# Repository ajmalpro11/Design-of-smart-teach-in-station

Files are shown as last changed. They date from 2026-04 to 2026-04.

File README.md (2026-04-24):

# Teach-In Station: Automated Warehouse Classification System

<p align="center">
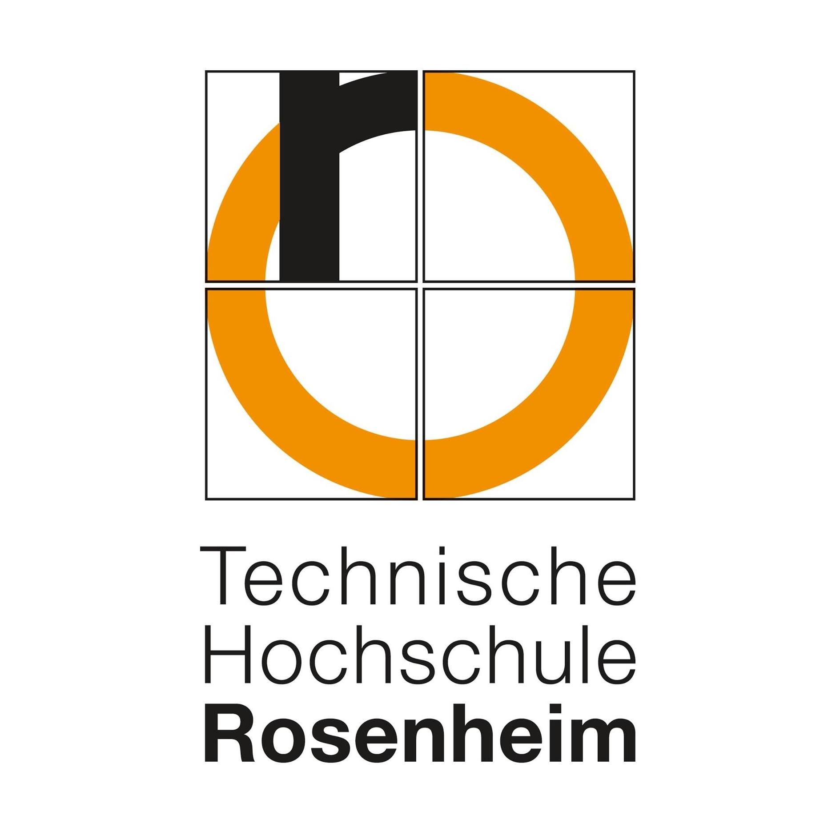
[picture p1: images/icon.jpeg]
  
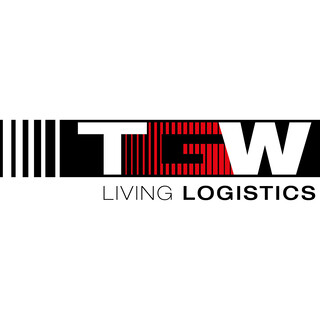
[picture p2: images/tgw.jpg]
  
</p>

**Mechanical Design | Summer Semester 2024** **Technische Hochschule Rosenheim | Group D** *In collaboration with TGW Logistics Group GmbH*

---

## 🏛️ Project Context
This project was developed as part of the **Mechanical Design** curriculum at **TH Rosenheim** for the Summer Semester 2024. The design was created in direct collaboration with **TGW Logistics Group GmbH** to solve real-world challenges in automated logistics.

## 📝 Project Overview
The "Teach-In Station" is an innovative solution designed to automate the identification of product attributes. Unlike standard systems that only track barcodes, this station analyzes:

<p align="center">
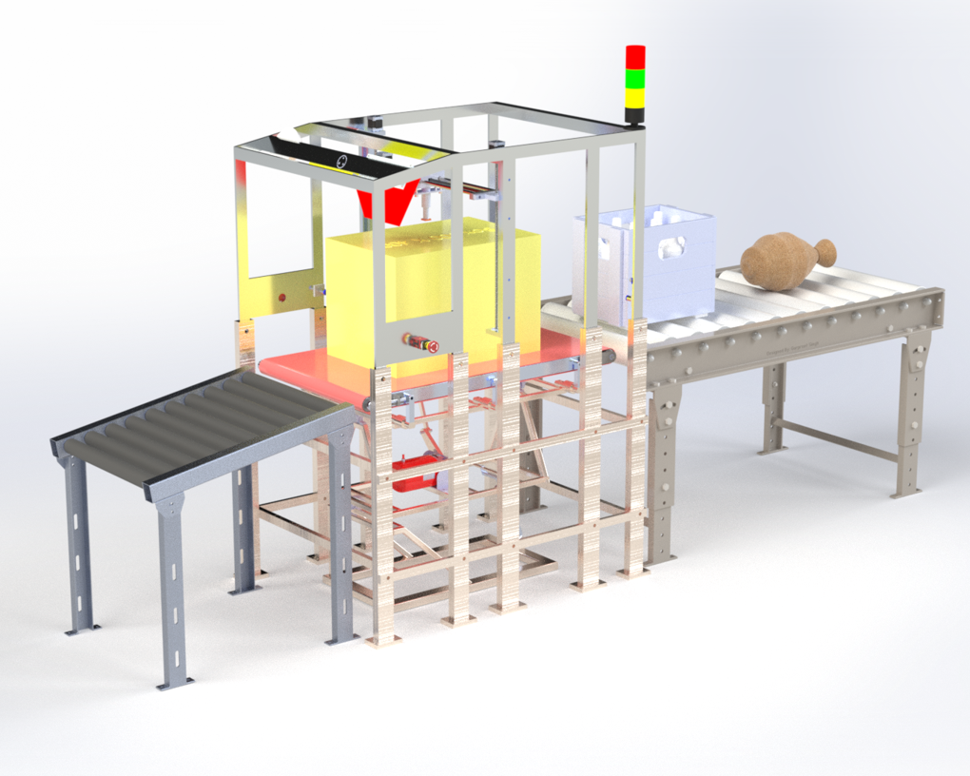
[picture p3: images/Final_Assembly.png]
  
</p> 

* **Physical Dimensions & Shape:** Identifying "Regular" vs. "Ugly" (irregular) objects using 3D camera profiling.
* **Stiffness:** Measuring structural integrity via a custom probe mechanism ($F = k \cdot \delta$).
* **Material Properties:** Detecting center of mass, liquid content (sloshing detection), and friction coefficients.

## 🛠️ System Assemblies
The repository contains design data for the following core modules:
1. **/Cage-Assembly:** The main structural frame housing the 3D camera, ultrasonic sensors, and weighing system.
2. **/Stiffness-Mechanism:** Precision assembly utilizing stepper motors, lead screws, and load cells for pressure testing.
3. **/Swivelling-Table:** A tilting platform designed for center of mass calculation and liquid detection.
4. **/Gravity-Conveyor:** The sorting mechanism for final product distribution.

## 📊 Technical Specifications
* **Final Concept:** Concept 7 (Selected for high reliability and space efficiency).
* **Total Estimated Cost:** **€9,118.76** (Budget limit: €15,000.00).
* **Software Logic:** Implementation of the **TGW Decision Code** (evaluating Weight, Dimensions, Geometry, and Stiffness).
* **Safety:** Integrated emergency stop, smoke detection, and optimized LED lighting for sensor precision.

## 👥 Group D Team Members
* Ajumal Shamsudeen 
* Aniket Barotkar
* Azmath Dar Khan
* Francis Almeida
* Udit Kumar
* Yazmin Soto

---

## 📂 Repository Structure
```text
├── docs/                 # Final Report and Technical Documentation
├── cad-models/           # STEP/STL files for all assemblies
├── images/          
├── logic/                # TGW Decision Code flowcharts and scripts
└── README.md             # Project Overview

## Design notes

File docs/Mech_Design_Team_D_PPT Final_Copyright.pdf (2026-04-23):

# MECHANICAL DESIGN

## THE DESIGN OF A SMART TEACH-IN STATION

08/07/2024

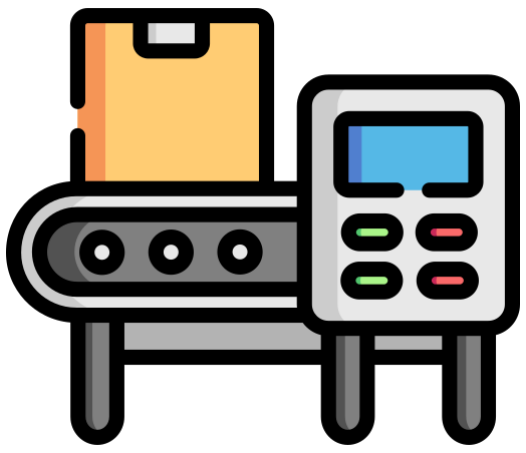
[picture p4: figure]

### Guided By: Dr. Ihab Ragai

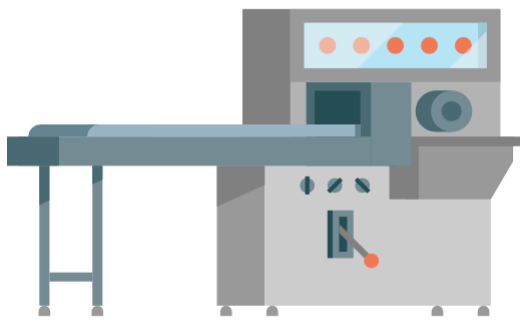
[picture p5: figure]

# Group-D

## Team members:

### •Ajumal Shamsudeen- 1067369 •Aniket Barotkar- 1066937 •Azmath Dar Khan- 1069574 •Francis Almeida- 1070842 •Udit Kumar- 1065691 •Yazmin Soto- 1066292

# TIMELINE

ABOUT PRESENTATION

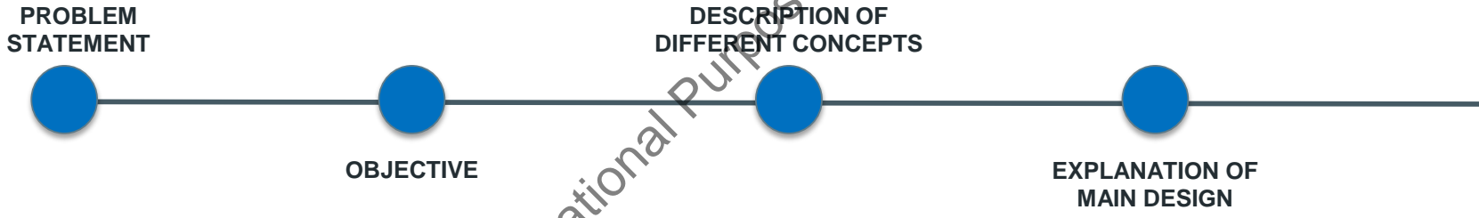
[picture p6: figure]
PROBLEM STATEMENT; OBJECTIVE; EXPLANATION OF; MAIN DESIGN; DESCRIPTION OF DIFFERENT CONCEPTS

# PROBLEM STATEMENT

- The absence of an effective solution for stacking different categories of products.

## - Designing a teach-In station for all products

- Avoid instabilities during transport and handling.
- Solid products to bottom, less stable products on top.
- Features of each product is to be measured.

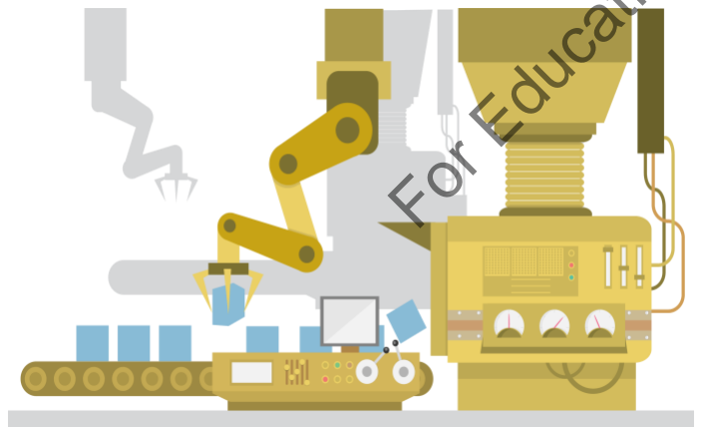
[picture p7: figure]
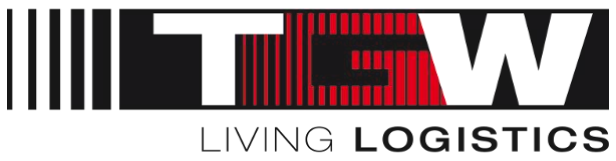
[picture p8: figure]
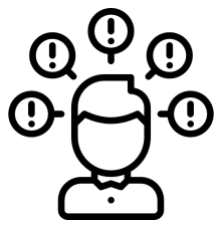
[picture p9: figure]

# OBJECTIVE

## 1. Identify the most suitable characteristic properties to measure the products: - Ensure rigidity - Detect defects (uglies) - Assess stackability - Facilitate product identification

## 2. The station is configurable as standalone device or as inline device

## 3. Product dimension range: from 120mm x 80mm x 40mm to 600mm x 400mm x 450mm

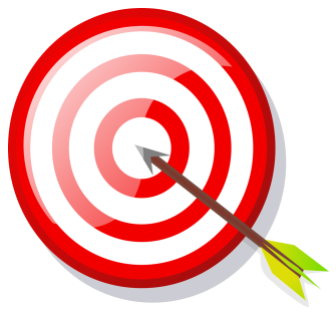
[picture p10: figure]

## 4. Product weight range: 0.5kg to 30kg

## 5. Operating speed: from 20 to 60 products per hour

# BRIEF INTRODUCTION ABOUT DIFFERENT CONCEPTS

CONCEPT-6 | Key Components: Focused on pre-installed devices like 3D scanners, RFID tags, and optical measurement devices. Benefits: Cost-effective, leveraging existing infrastructure. Limitations: Limited versatility and potential integration issues.
CONCEPT-5 | Key Components: Machine vision system for stiffness calculations and product identification (new vs. regular). Benefits: Effective for identifying product history and stiffness. Limitations: Potential issues with the accuracy and complexity of machine vision algorithms.
CONCEPT-4 | Key Components: Similar to Concept 2 with an X-ray machine but incorporated different secondary components. Benefits: Maintained benefits of X-ray precision. Limitations: Shared the high cost issue with Concept 2, leading to its rejection.
CONCEPT-3 | Key Components: Thermal imaging for liquid detection and stiffness measurement. Benefits: Non-contact measurement method, useful for detecting liquid presence. Limitations: Reliability issues at high temperatures made this concept impractical.
CONCEPT-2 | Key Components: X-ray machine for object identification and stiffness measurement by detecting thickness. Benefits: Accurate internal structure analysis. Limitations: High cost of X-ray machines led to the discontinuation of this concept.
CONCEPT-1 | Key Components: Utilized a 3D camera for measuring dimensions, calculating stiffness, and object identification. Benefits: High precision in dimension and stiffness measurements, effective object identification. Limitations: Complexity and potential high cost of whole system.

# BRIEF INTRODUCTION ABOUT DIFFERENT CONCEPTS

CONCEPT-6 | Key Components: Focused on pre-installed devices like 3D scanners, RFID tags, and optical measurement devices. Benefits: Cost-effective, leveraging existing infrastructure. Limitations: Limited versatility and potential integration issues.
CONCEPT-5 | Key Components: Machine vision system for stiffness calculations and product identification (new vs. regular). Benefits: Effective for identifying product history and stiffness. Limitations: Potential issues with the accuracy and complexity of machine vision algorithms.
CONCEPT-4 | Key Components: Similar to Concept 2 with an X-ray machine but incorporated different secondary components. Benefits: Maintained benefits of X-ray precision. Limitations: Shared the high cost issue with Concept 2, leading to its rejection.
CONCEPT-3 | Key Components: Thermal imaging for liquid detection and stiffness measurement. Benefits: Non-contact measurement method, useful for detecting liquid presence. Limitations: Reliability issues at high temperatures made this concept impractical.
CONCEPT-2 | Key Components: X-ray machine for object identification and stiffness measurement by detecting thickness. Benefits: Accurate internal structure analysis. Limitations: High cost of X-ray machines led to the discontinuation of this concept.
CONCEPT-1 | Key Components: Utilized a 3D camera for measuring dimensions, calculating stiffness, and object identification. Benefits: High precision in dimension and stiffness measurements, effective object identification. Limitations: Complexity and potential high cost of whole system.

# BRIEF INTRODUCTION ABOUT DIFFERENT CONCEPTS

CONCEPT-6 | Key Components: Focused on pre-installed devices like 3D scanners, RFID tags, and optical measurement devices. Benefits: Cost-effective, leveraging existing infrastructure. Limitations: Limited versatility and potential integration issues.
CONCEPT-5 | Key Components: Machine vision system for stiffness calculations and product identification (new vs. regular). Benefits: Effective for identifying product history and stiffness. Limitations: Potential issues with the accuracy and complexity of machine vision algorithms.
CONCEPT-4 | Key Components: Similar to Concept 2 with an X-ray machine but incorporated different secondary components. Benefits: Maintained benefits of X-ray precision. Limitations: Shared the high cost issue with Concept 2, leading to its rejection.

CONCEPT-3
Key Components: Thermal imaging for liquid detection and stiffness measurement. Benefits: Non-contact measurement method, useful for detecting liquid presence. Limitations: Reliability issues at high temperatures made this concept impractical.
CONCEPT-2 | Key Components: X-ray machine for object identification and stiffness measurement by detecting thickness. Benefits: Accurate internal structure analysis. Limitations: High cost of X-ray machines led to the discontinuation of this concept.
CONCEPT-1 | Key Components: Utilized a 3D camera for measuring dimensions, calculating stiffness, and object identification. Benefits: High precision in dimension and stiffness measurements, effective object identification. Limitations: Complexity and potential high cost of whole system.

# BRIEF INTRODUCTION ABOUT DIFFERENT CONCEPTS

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

# BRIEF INTRODUCTION ABOUT DIFFERENT CONCEPTS

CONCEPT-6 | Key Components: Focused on pre-installed devices like 3D scanners, RFID tags, and optical measurement devices. Benefits: Cost-effective, leveraging existing infrastructure. Limitations: Limited versatility and potential integration issues.
CONCEPT-5 | Key Components: Machine vision system for stiffness calculations and product identification (new vs. regular). Benefits: Effective for identifying product history and stiffness. Limitations: Potential issues with the accuracy and complexity of machine vision algorithms.
CONCEPT-4 | Key Components: Similar to Concept 2 with an X-ray machine but incorporated different secondary components. Benefits: Maintained benefits of X-ray precision. Limitations: Shared the high cost issue with Concept 2, leading to its rejection.
CONCEPT-3 | Key Components: Thermal imaging for liquid detection and stiffness measurement.
| Benefits: Non-contact measurement method, useful for detecting liquid presence. Limitations: Reliability issues at high temperatures made this concept impractical.
CONCEPT-2 | Key Components: X-ray machine for object identification and stiffness measurement by detecting thickness. Benefits: Accurate internal structure analysis. Limitations: High cost of X-ray machines led to the discontinuation of this concept.
CONCEPT-1 | Key Components: Utilized a 3D camera for measuring dimensions, calculating stiffness, and object identification. Benefits: High precision in dimension and stiffness measurements, effective object identification. Limitations: Complexity and potential high cost of whole system.

# BRIEF INTRODUCTION ABOUT DIFFERENT CONCEPTS

CONCEPT-6
Key Components: Focused on devices like 3D scanners, RFID tags, and optical measurement devices. Benefits: Leveraging existing infrastructure.
Limitations: Limited versatility and multiple complex system which result in high cost.
CONCEPT-5 | Key Components: Machine vision system for stiffness calculations and product identification (new vs. regular). Benefits: Effective for identifying product history and stiffness. Limitations: Potential issues with the accuracy and complexity of machine vision algorithms.
CONCEPT-4 | Key Components: Similar to Concept 2 with an X-ray machine but incorporated different secondary components. Benefits: Maintained benefits of X-ray precision. Limitations: Shared the high cost issue with Concept 2, leading to its rejection.
CONCEPT-3 | Key Components: Thermal imaging for liquid detection and stiffness measurement. Benefits: Non-contact measurement method, useful for detecting liquid presence. Limitations: Reliability issues at high temperatures made this concept impractical.
CONCEPT-2 | Key Components: X-ray machine for object identification and stiffness measurement by detecting thickness. Benefits: Accurate internal structure analysis. Limitations: High cost of X-ray machines led to the discontinuation of this concept.
CONCEPT-1 | Key Components: Utilized a 3D camera for measuring dimensions, calculating stiffness, and object identification. Benefits: High precision in dimension and stiffness measurements, effective object identification. Limitations: Complexity and potential high cost of whole system.

# FINAL CONCEPT

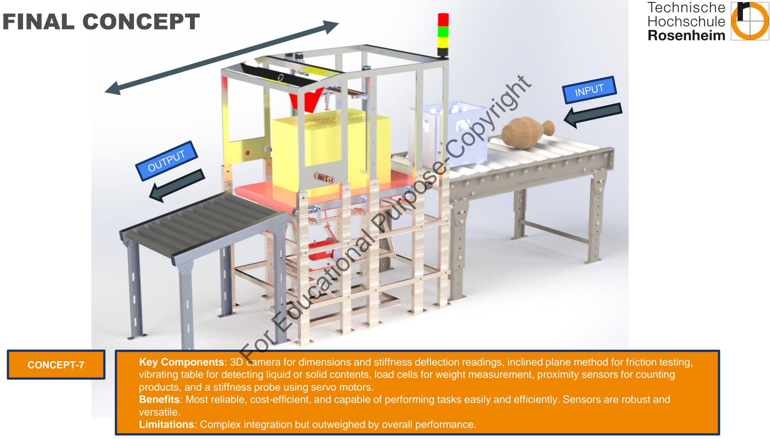
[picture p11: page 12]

CONCEPT-7 | Key Components: 3D camera for dimensions and stiffness deflection readings, inclined plane method for friction testing, vibrating table for detecting liquid or solid contents, load cells for weight measurement, proximity sensors for counting products, and a stiffness probe using servo motors. Benefits: Most reliable, cost-efficient, and capable of performing tasks easily and efficiently. Sensors are robust and versatile. Limitations: Complex integration but outweighed by overall performance.

# PHYSICAL SIZES

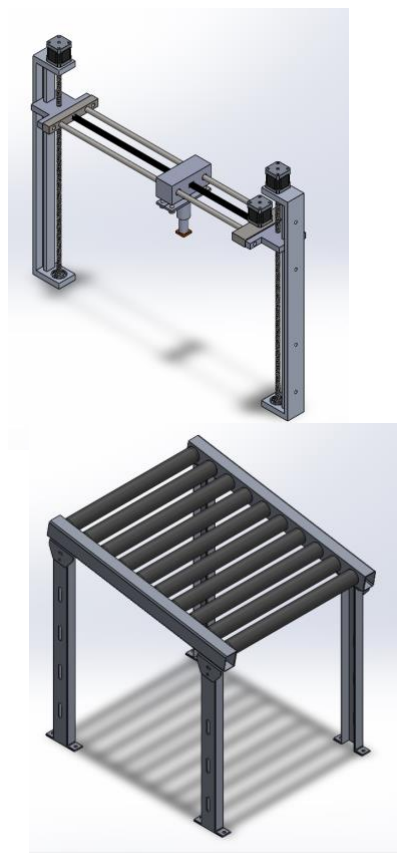
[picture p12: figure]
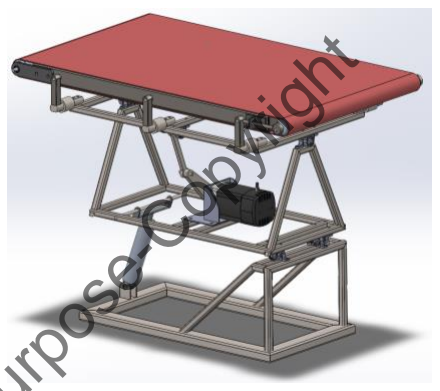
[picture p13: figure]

### 1.Table Dimensions: •1000 mm (Length) × 650 mm (Width) × 600 mm (Height)

### 2.Stiffness Assembly Dimensions: •150 mm (Length) × 780 mm (Width) × 630 mm (Height)

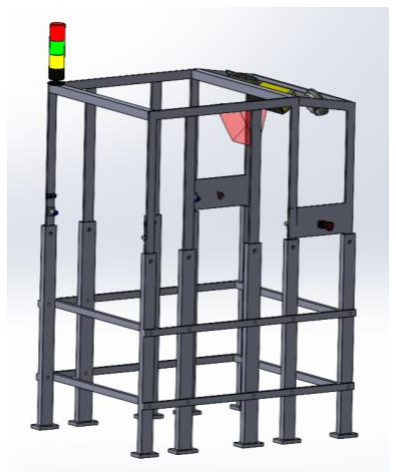
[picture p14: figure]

### 3.Legs for Cage Dimensions: •1120 mm (Length) × 850 mm (Width) × 900 mm (Height)

### 4.Cage Assembly Dimensions: •1100 mm (Length) × 800 mm (Width) × 700 mm (Height)

### 5.Gravity Conveyor Dimensions: •750 mm (Length) × 620 mm (Width) × 785 mm (Height)

# FLOW CHARTS

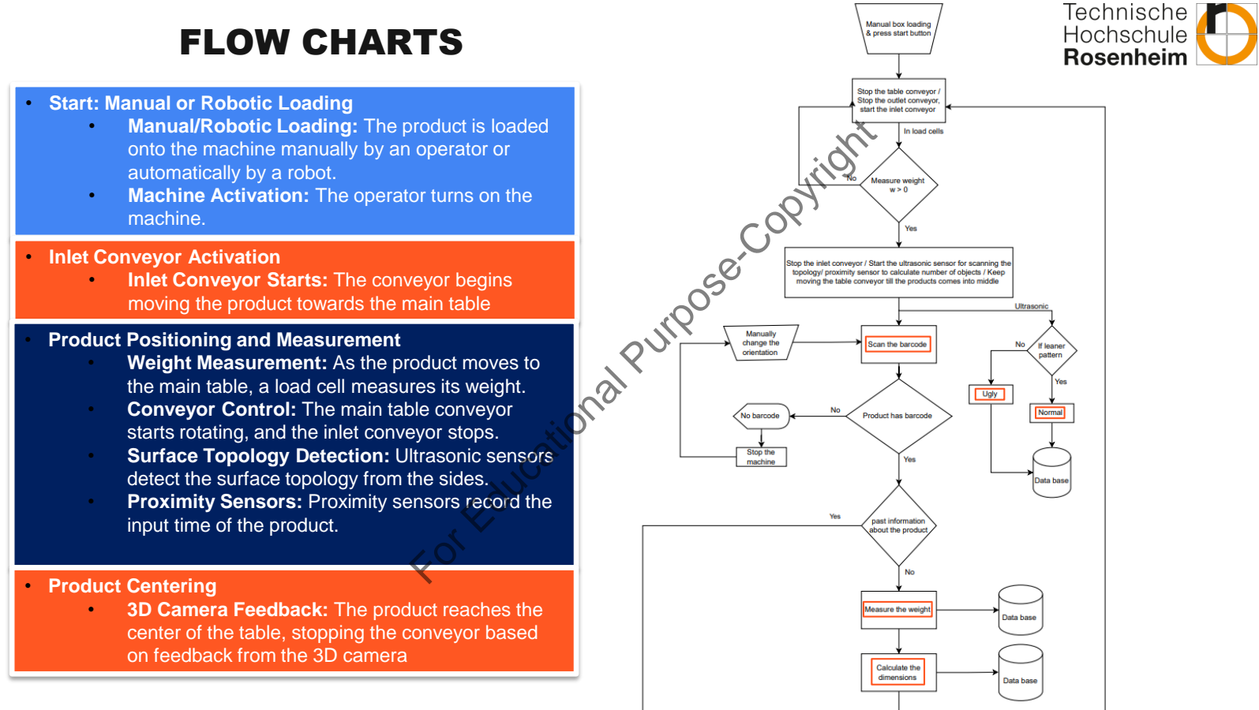
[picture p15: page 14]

- Start: Manual or Robotic Loading
- Manual/Robotic Loading: The product is loaded onto the machine manually by an operator or automatically by a robot.
- Machine Activation: The operator turns on the machine.
- Inlet Conveyor Activation
- Inlet Conveyor Starts: The conveyor begins moving the product towards the main table
- Product Positioning and Measurement
- Weight Measurement: As the product moves to the main table, a load cell measures its weight.
- Conveyor Control: The main table conveyor starts rotating, and the inlet conveyor stops.
- Surface Topology Detection: Ultrasonic sensors detect the surface topology from the sides.
- Proximity Sensors: Proximity sensors record the input time of the product.
- Product Centering
- 3D Camera Feedback: The product reaches the center of the table, stopping the conveyor based on feedback from the 3D camera

# FLOW CHARTS

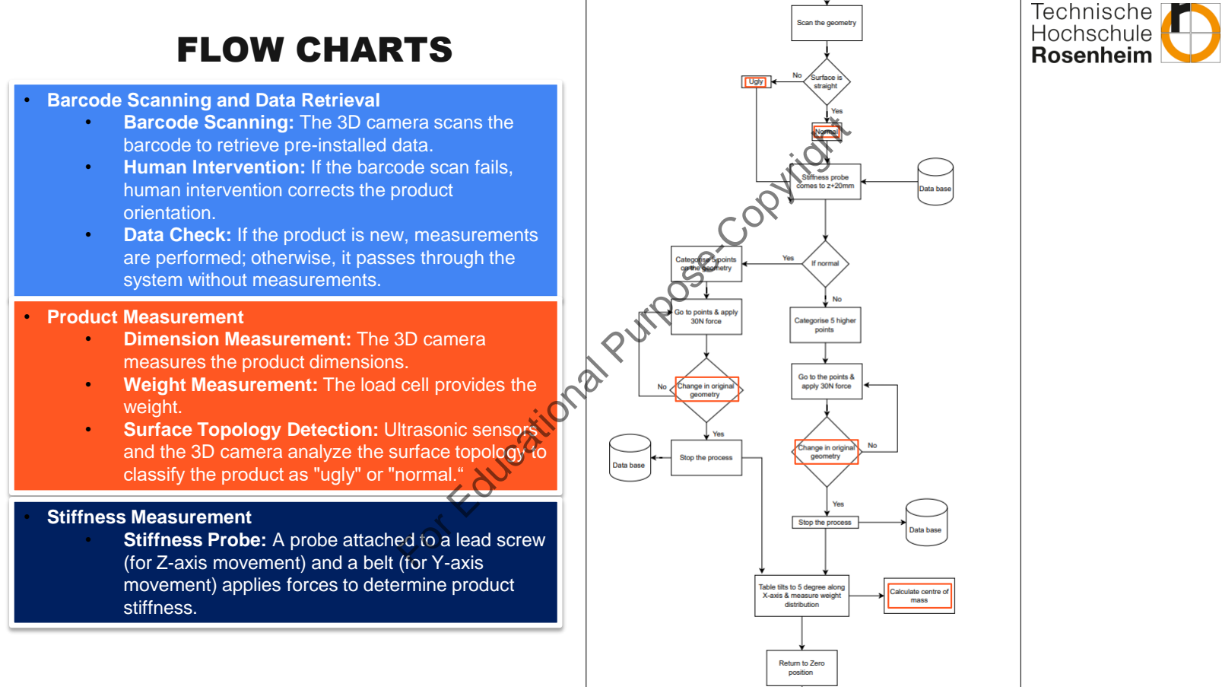
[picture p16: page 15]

- Barcode Scanning and Data Retrieval
- Barcode Scanning: The 3D camera scans the barcode to retrieve pre-installed data.
- Human Intervention: If the barcode scan fails, human intervention corrects the product orientation.
- Data Check: If the product is new, measurements are performed; otherwise, it passes through the system without measurements.
- Product Measurement
- Dimension Measurement: The 3D camera measures the product dimensions.
- Weight Measurement: The load cell provides the weight.
- Surface Topology Detection: Ultrasonic sensors and the 3D camera analyze the surface topology to classify the product as "ugly" or "normal.“
- Stiffness Measurement
- Stiffness Probe: A probe attached to a lead screw (for Z-axis movement) and a belt (for Y-axis movement) applies forces to determine product stiffness.

# FLOW CHARTS

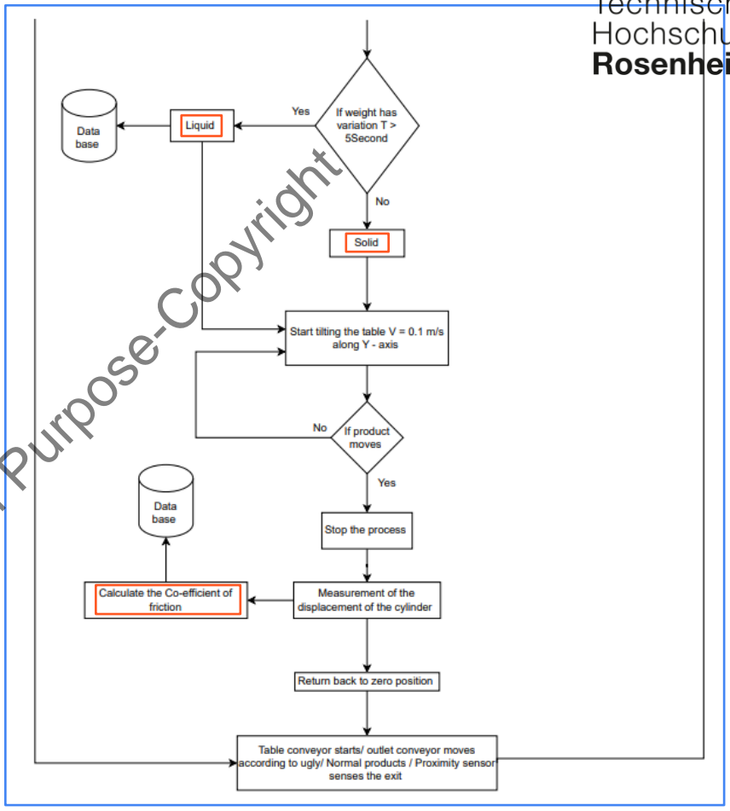
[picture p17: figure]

- This flowchart illustrates the step-by-step operation of the machine, from loading to the final sorting of the product.
- Center of Mass Calculation and Liquid/Solid Test
- Table Tilting (X-axis): The table tilts ±5 degrees to measure weight variation and determine if the product is liquid or solid.
- Returning to Zero Position: After tilting, the table returns to its zero position.
- Coefficient of Friction Calculation
- Table Tilting (Y-axis): The table tilts along the Y-axis until the product starts moving.
- Angle Measurement: The angle at which the product starts moving is used to calculate the coefficient of friction.
- Completion and Sorting
- Return to Zero Position: The table returns to its zero position after calculations.
- Conveyor Activation: The table conveyor starts moving again.
- Outlet Conveyor Direction: The outlet conveyor directs the product based on its classification ("ugly" or "normal").
- End: Process Completion
- Process Ends: The product is sorted and the process completes.

# ESTIMATED TIME TAKEN

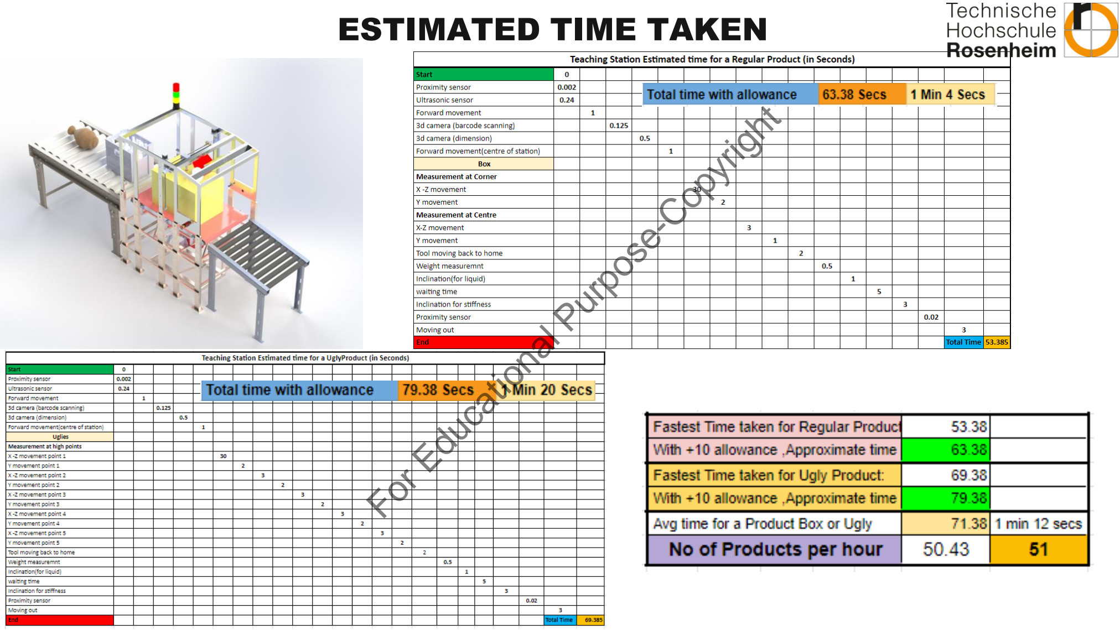
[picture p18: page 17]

# OPERATORS ACTION

## Operator Actions in Machine Operation

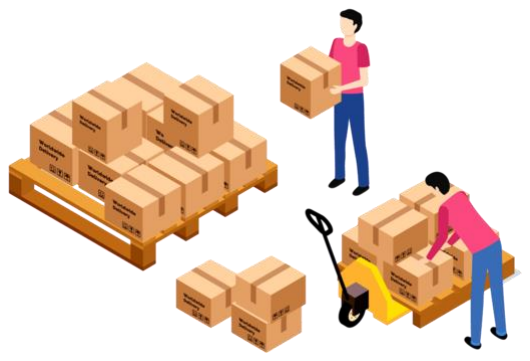
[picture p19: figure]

## 1.Loading: - Manual Loading: Operator manually loads boxes onto the Inlet conveyor - Robotic Loading: Boxes are loaded onto the Inlet conveyor using a

robotic system.

## 2.System Activation:

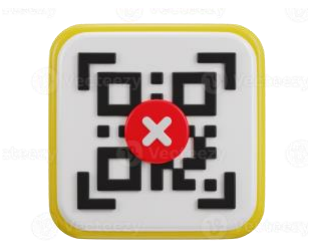
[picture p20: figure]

Operator starts the system, initiating the entire machine operation.

## 3.Manual Orientation Adjustment: If the 3D scanner is unable to scan the barcode, the operator manually

adjusts the orientation of the boxes.

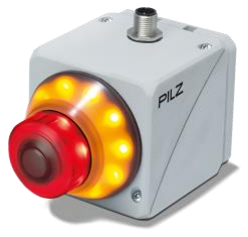
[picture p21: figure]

## 4.Emergency Procedures: In case of an emergency or malfunction, the operator presses the

emergency stop button to ensure safety.

## Note: A single qualified trainee is required for handling this teach-in station

# COST ESTIMATION

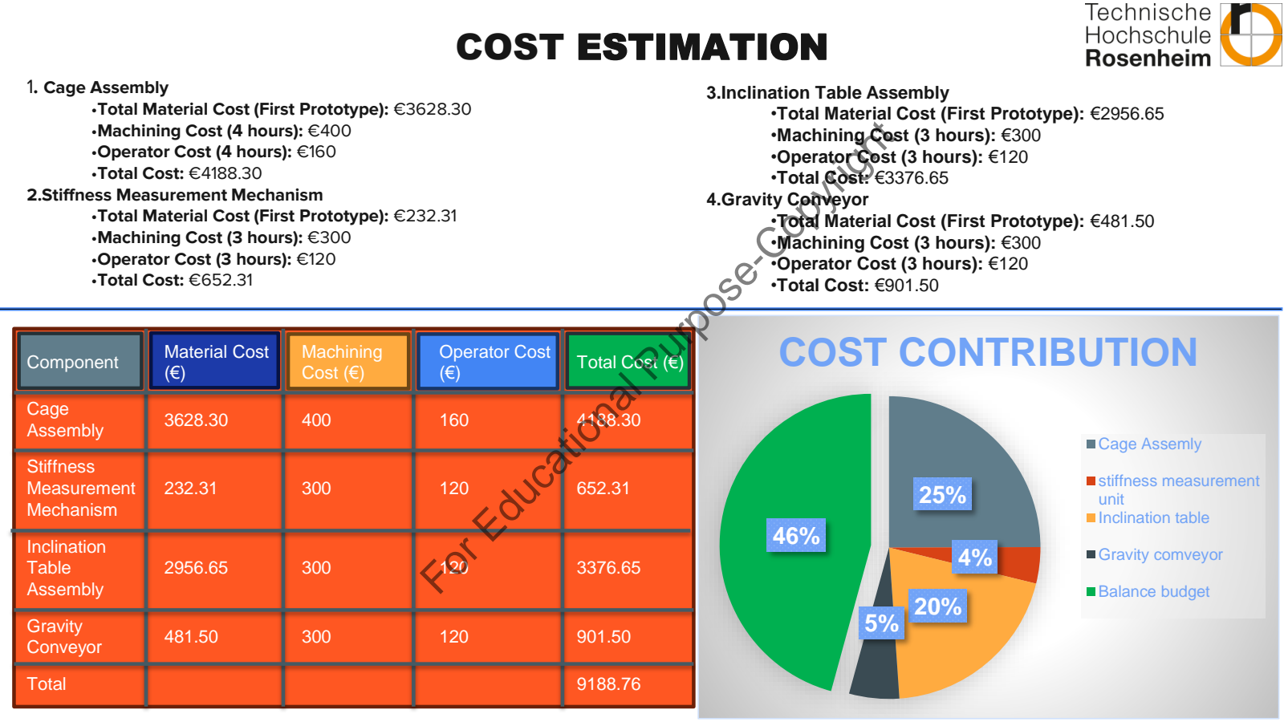
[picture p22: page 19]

25%

4%

20%
5%

46%

# COST CONTRIBUTION

Cage Assemly

stiffness measurement
unit
Inclination table

Gravity comveyor

Balance budget

1. Cage Assembly
•Total Material Cost (First Prototype): €3628.30 •Machining Cost (4 hours): €400
•Operator Cost (4 hours): €160
•Total Cost: €4188.30
2.Stiffness Measurement Mechanism
•Total Material Cost (First Prototype): €232.31 •Machining Cost (3 hours): €300
•Operator Cost (3 hours): €120
•Total Cost: €652.31

3.Inclination Table Assembly
•Total Material Cost (First Prototype): €2956.65 •Machining Cost (3 hours): €300
•Operator Cost (3 hours): €120
•Total Cost: €3376.65
4.Gravity Conveyor
•Total Material Cost (First Prototype): €481.50 •Machining Cost (3 hours): €300
•Operator Cost (3 hours): €120
•Total Cost: €901.50
Component | Material Cost (€) | Machining Cost (€) | Operator Cost (€) | Total Cost (€)
Cage Assembly | 3628.30 | 400 | 160 | 4188.30
Stiffness Measurement Mechanism | 232.31 | 300 | 120 | 652.31
Inclination Table Assembly | 2956.65 | 300 | 120 | 3376.65

Gravity
Conveyor | 481.50 | 300 | 120 | 901.50
Total | | | | 9188.76

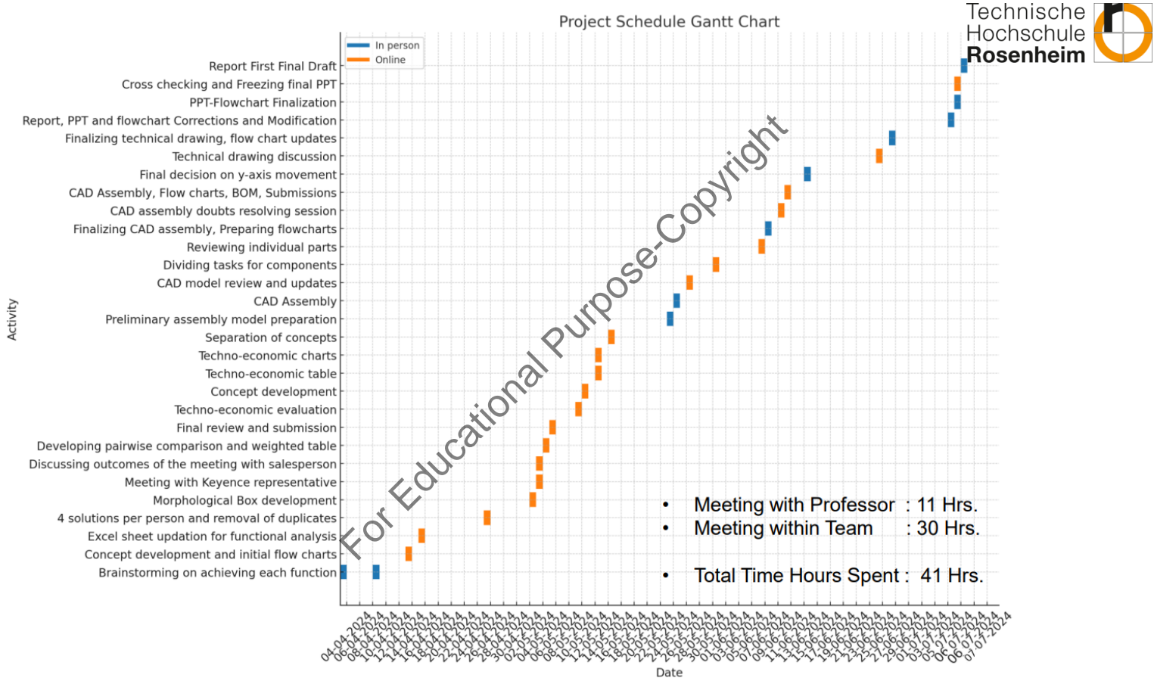
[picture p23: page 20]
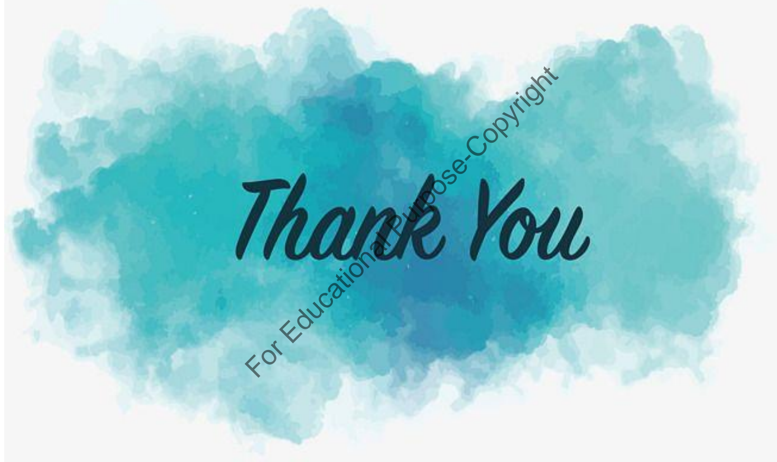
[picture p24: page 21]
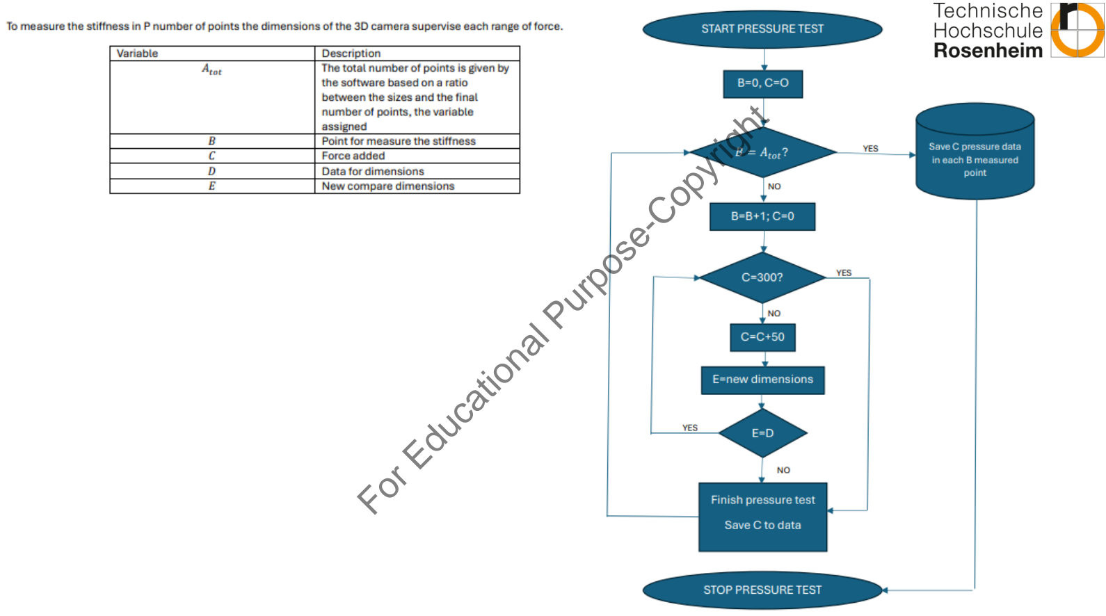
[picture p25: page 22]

# Determination of Centre of Mass

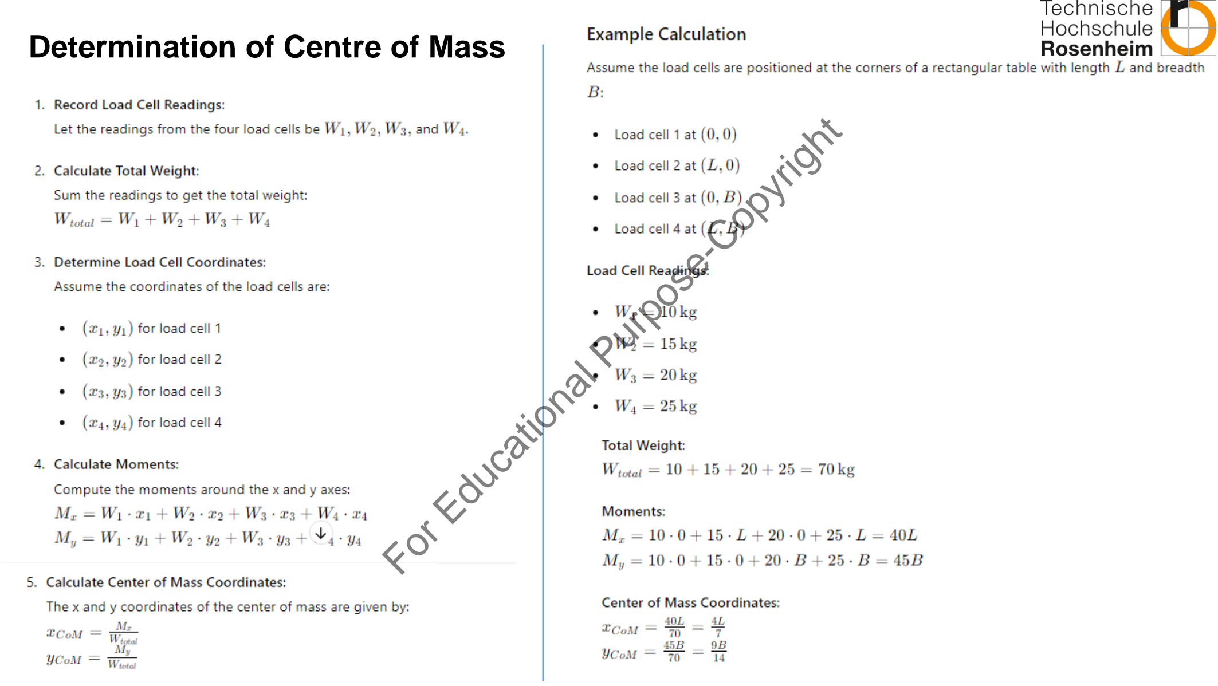
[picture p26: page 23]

## Determination of Centre of Mass –in 3D

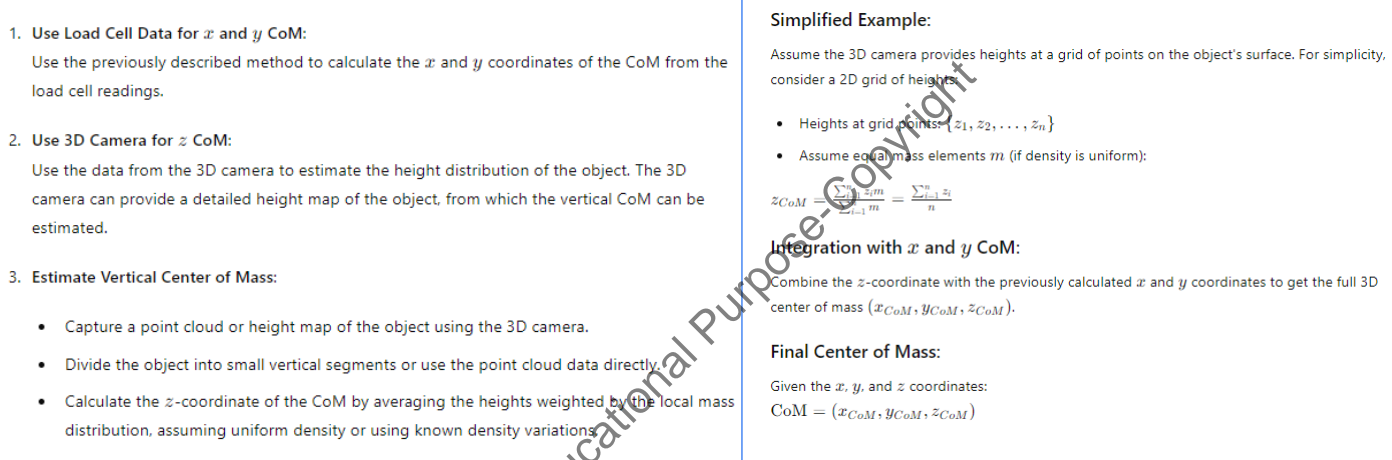
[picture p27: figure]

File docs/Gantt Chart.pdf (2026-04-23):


- Meeting with Professor : 11 Hrs.
- | Meeting within Team | : 30 Hrs.
- Total Time Hours Spent : 41 Hrs.

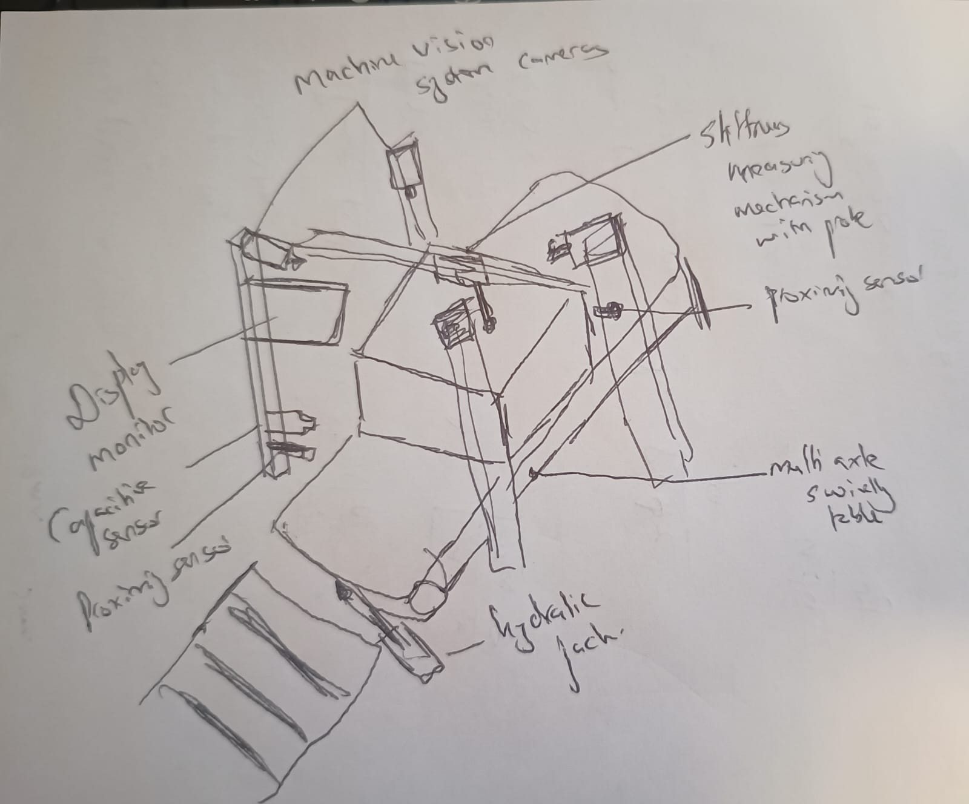
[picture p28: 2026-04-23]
images/concept 6.jpg

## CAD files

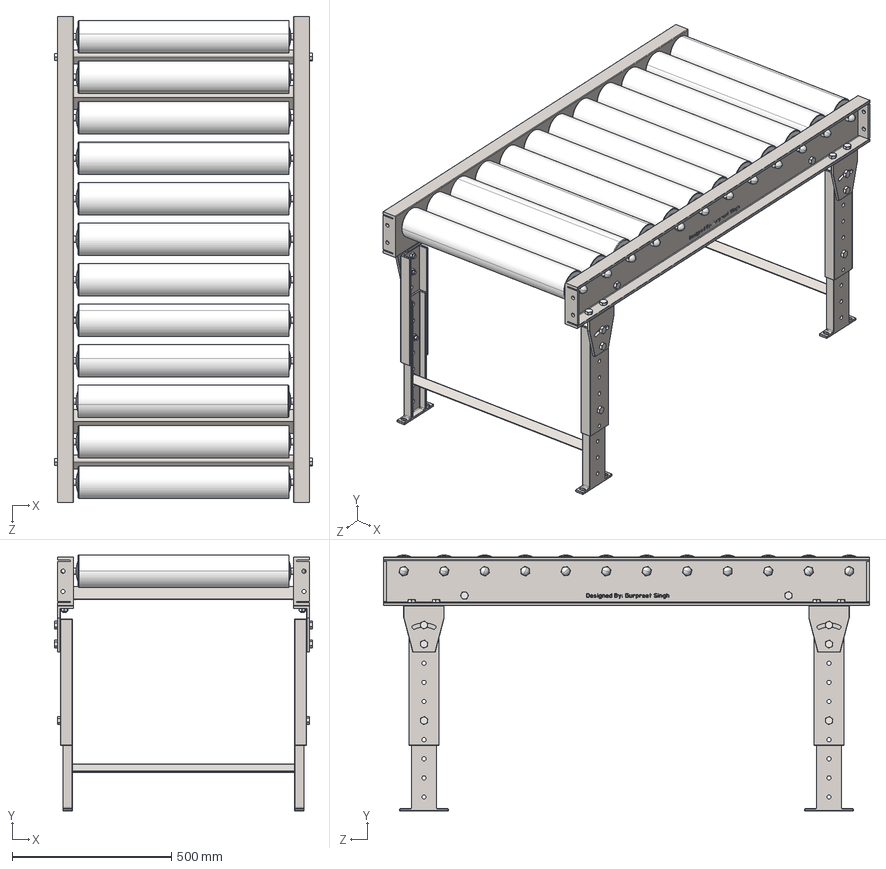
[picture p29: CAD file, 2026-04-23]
cad-models/Assembly of Rollars and Frame.STEP
809.7 x 802.6 x 1524.0 mm
c channel x 2
Rollar part 1 x 12
Rollar part 2 x 24
Rollar part 3 Bearing x 24
Rollar part 4 shaft x 12
Rollar part 5 seal x 24
Rollar part 6 Nut_91855A530 x 24
Support to connect frame x 2
heavy hex bolt_ai_HHBOLT 0.5000-20x1.5x1-N x 4
flat washer type a selected narrow_ai_Selected Narrow FW 0.5 x 4
hex jam nut_ai_HJNUT 0.5000-20-D-N x 24
Frame part 1 x 4
Frame part 2 x 4
Frame part 3 x 2
heavy hex bolt_ai_HHBOLT 0.5000-20x1.25x1-N x 20

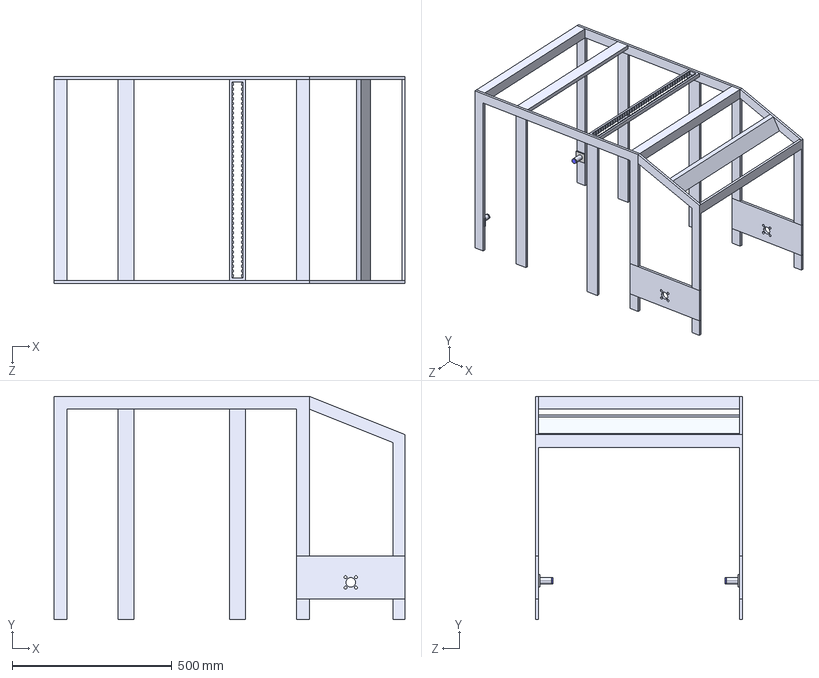
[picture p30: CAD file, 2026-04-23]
cad-models/Teaching station frame.STEP
1100.0 x 700.0 x 650.0 mm

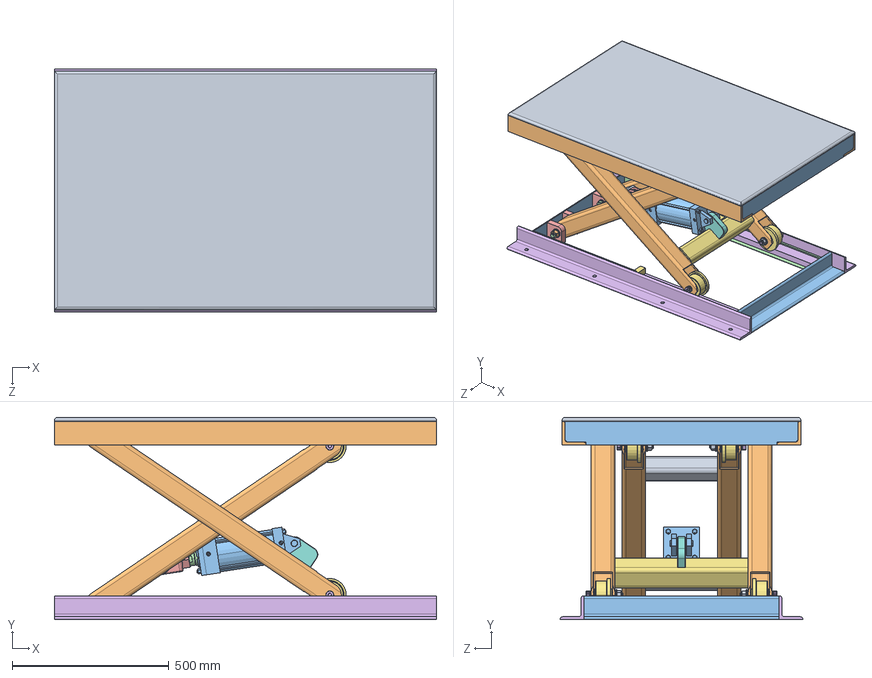
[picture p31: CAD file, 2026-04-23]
cad-models/LIFT TABLE, SCISSOR LIFT.STEP
1219.2 x 646.0 x 774.7 mm
TABLE_Default<As Machined>
LEG-A1_Default<As Machined> x 4
91257A860_HIGH-STRENGTH GRADE 8 STEEL CAP SCREW, .750-10 X 6.50L_91257A860 x 4
90126A036_ZINC-PLATED STEEL SAE FLAT WASHER, ﾘ.750_90126A036 x 6
91259A848_ALLOY STEEL SHOULDER SCREW, ﾘ.75 X 3.25L, .625-11 X .88L_91259A848 x 4
2353T26_FLANGED TRACK WHEEL, ﾘ3.50 X 1.44 W, FOR ﾘ.75 AXLE. x 4
90126A035_ZINC-PLATED STEEL SAE FLAT WASHER, ﾘ.625_90126A035 x 4
94895A035_ZINC YELLOW-CHROMATE PLATED STEEL HEX NUT, .625-11_94895A035 x 4
94895A036_ZINC YELLOW-CHROMATE PLATED STEEL HEX NUT, .750-10_94895A036 x 2
BOTTOM FRAME_Default<As Machined>
CYLINDER MOUNT_Default<As Machined>
CYLINDER CONNECTION_Default<As Machined>
2A-Body-Bore4.00_x
2A-Rod-Bore4.00-Rod4-STD_x
CYLINDER SPACER_Default<As Machined>

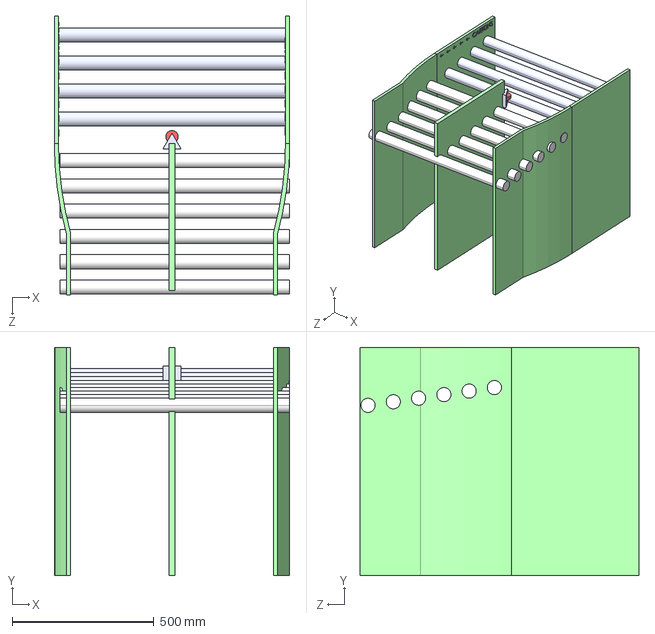
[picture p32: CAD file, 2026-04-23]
cad-models/Seperation rollers.STEP
830.0 x 805.1 x 984.0 mm

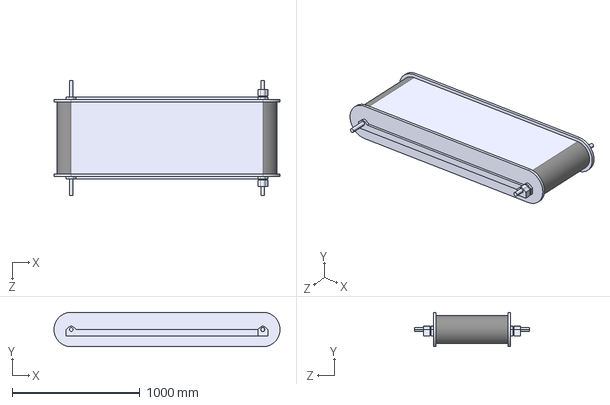
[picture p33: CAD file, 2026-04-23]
cad-models/Belt Pulley.STEP
1769.7 x 270.0 x 900.0 mm

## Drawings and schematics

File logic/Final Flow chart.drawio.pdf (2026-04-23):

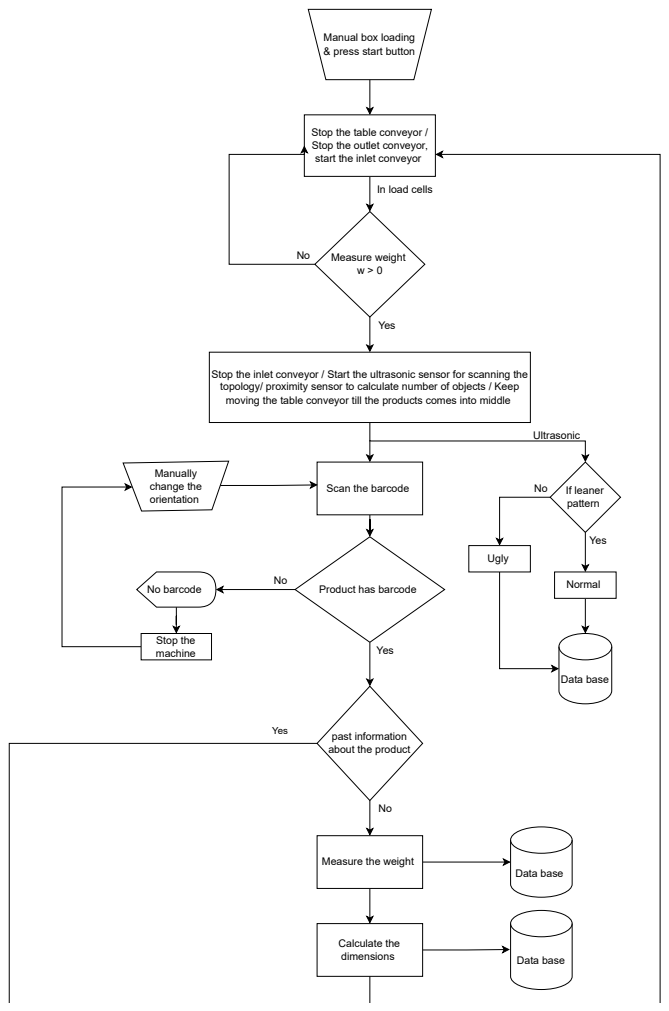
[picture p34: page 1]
Measure weight w > 0; No barcode; Product has barcode; Manually change the orientation; Stop the machine; Yes; past information; Calculate the dimensions; Data base; If leaner pattern; Normal; Ugly; Ultrasonic

Manual box loading
& press start button

Stop the table conveyor /
Stop the outlet conveyor,
start the inlet conveyor

In load cells

Stop the inlet conveyor / Start the ultrasonic sensor for scanning the
topology/ proximity sensor to calculate number of objects / Keep
moving the table conveyor till the products comes into middle

Scan the barcode

about the product

Measure the weight

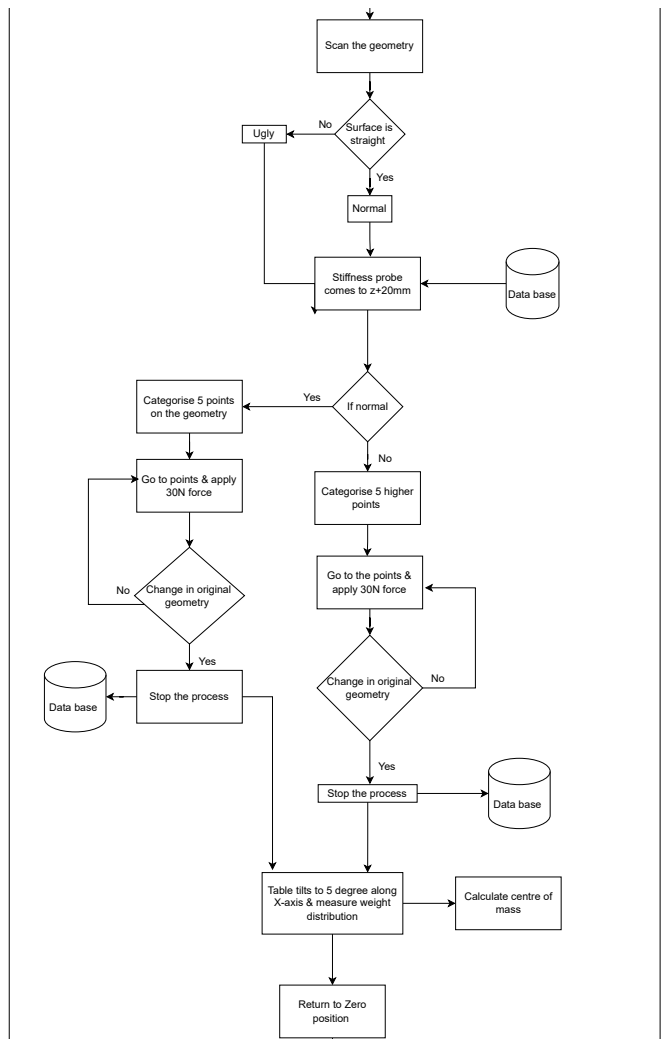
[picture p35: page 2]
Surface is straight Ugly; Normal; Stiffness probe; comes to z+20mm; Data base; Categorise 5 higher points; geometry; Yes

Scan the geometry

If normal Categorise 5 points
on the geometry

Go to points & apply
30N force

Go to the points &
apply 30N force

Change in original

geometry

Stop the process

Table tilts to 5 degree along
X-axis & measure weight
distribution

Calculate centre of
mass

Return to Zero
position

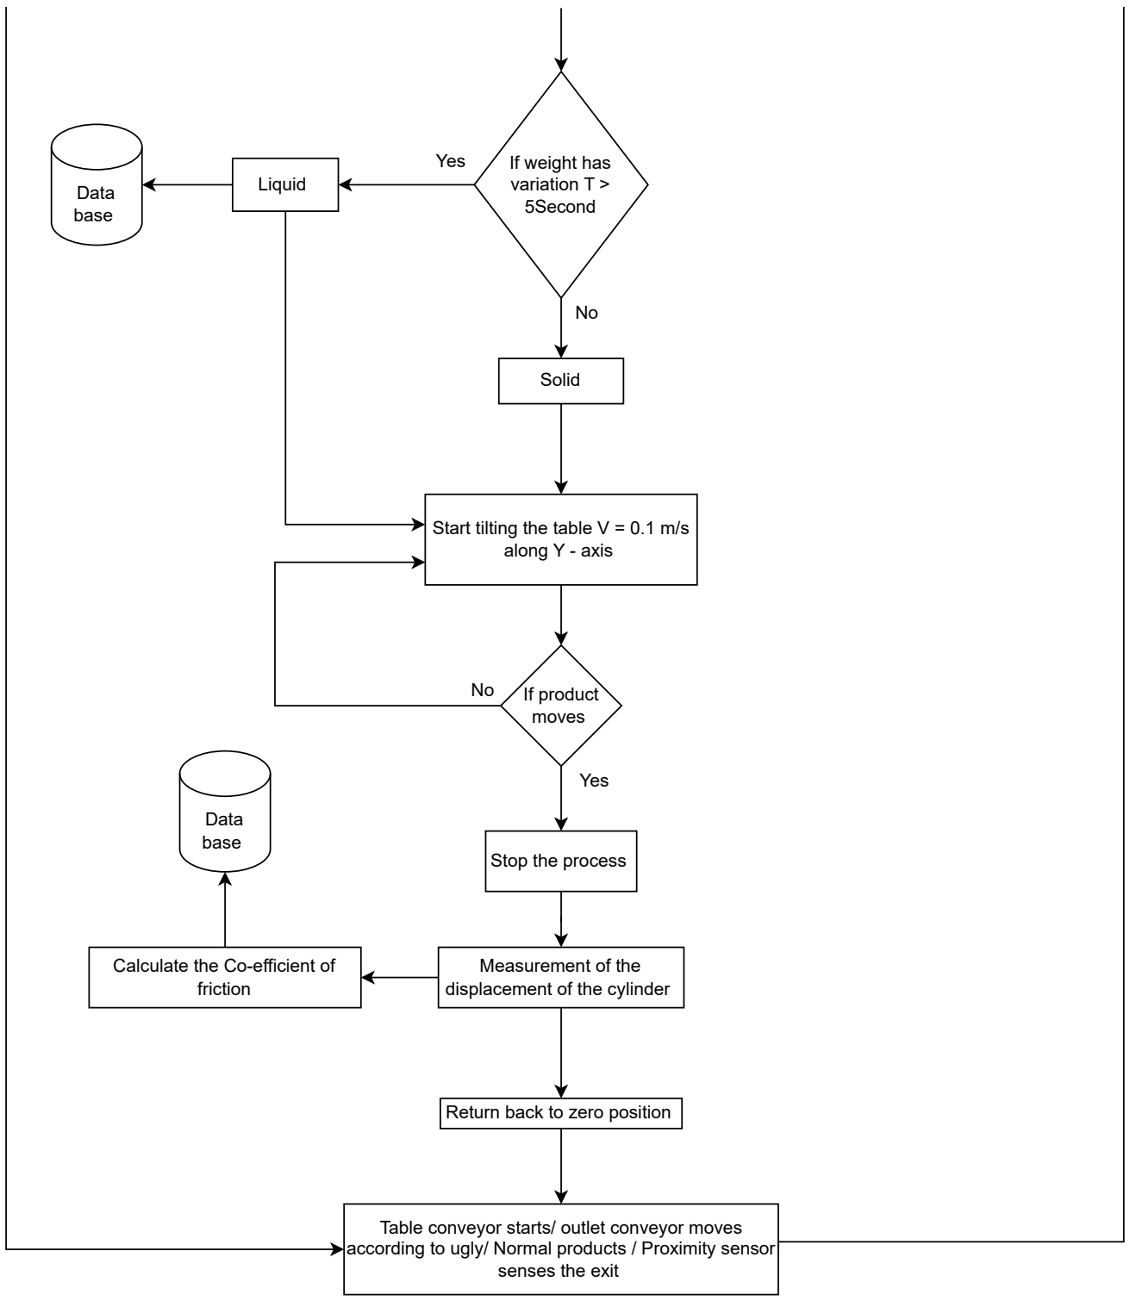
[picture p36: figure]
If weight has variation T > 5Second; Liquid; Solid; Data base; Start tilting the table V = 0.1 m/s along Y - axis; Yes; If product moves; Stop the process; Measurement of the displacement of the cylinder; Calculate the Co-efficient of friction; Return back to zero position; senses the exit

Table conveyor starts/ outlet conveyor moves according to ugly/ Normal products / Proximity sensor
